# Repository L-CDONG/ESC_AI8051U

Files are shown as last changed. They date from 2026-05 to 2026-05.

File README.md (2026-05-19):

# STC8051U BLDC ESC – 无传感器无刷电子调速器

基于 **STC8051U** 单片机设计的 **无传感器无刷直流电机（BLDC）电子调速器（ESC）**，适用于无人机、小型电动工具

Snipaste_2026-05-19_12-56-54
Snipaste_2026-05-19_12-57-10

---

## 特性

- **主控芯片**：STC8051U（增强型8051内核，内置比较器/ADC，硬件PWM）
- **控制方式**：无传感器六步换向（120° 导通方式）
- **位置检测**：反电动势（BEMF）过零点检测，无需霍尔传感器
- **调制方式**：上桥臂PWM调制 + 下桥臂恒通（或互补PWM，根据配置可选）
- **启动方式**：三段式启动（预定位 → 强制换向 → 同步运行）
- **保护功能**：过流保护（通过ADC采样）、堵转保护、欠压保护
- **参数配置**：可通过串口（UART）在线调节PWM频率、启动参数等
- **开源协议**：MIT

---

## 工作原理

### 1. 六步换向法
三相BLDC的六个导通顺序（AB → AC → BC → BA → CA → CB），每60°电角度切换一次，每次导通两相（一相高端PWM，一相低端ON，第三相悬空）。

### 2. 反电动势过零点检测
- 悬空相的端电压与虚拟中性点电压比较（利用芯片内部比较器或外部电阻分压网络）
- 当BEMF过零点发生后，延迟30°电角度执行换相
- STC8051U内置比较器可直接用于过零检测，无需外部比较器芯片

### 3. 闭环控制
通过PWM占空比调节电机转速，根据换相周期计算实时转速，实现速度闭环（可扩展）。

---

## 硬件设计

### 主要元件清单

| 元件 | 型号/参数 | 数量 |
|---|---|---|
| MCU | STC8051U-40I-LQFP48 | 1 |
| MOSFET 驱动 | EG2181 / IR2101 (半桥) | 3 |
| N-MOSFET | 根据电压电流选择 (如 IRFS3607) | 6 |
| 电流采样电阻 | 0.001Ω ~ 0.01Ω 功率电阻 | 1 |
| 电压采样电阻分压 | 用于母线电压、反电动势 | 若干 |

### 典型电路结构

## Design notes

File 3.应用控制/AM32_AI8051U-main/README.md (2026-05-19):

# 80251 ESC Base on AI8051U

* [AM32](https://github.com/am32-firmware/AM32)<br>
* [ESC_Config_Tool](https://am32.ca/downloads)<br>
* [Bootloader](https://github.com/Icey7122/AM32_Bootloader_AI8051U)<br>

## Introduction
The AM32 firmware has been ported to the 80251 platform, and the controller has chosen as AI8051U. It can be compiled on Keil C251. At the same time, the bootloader program has been ported, and tool of Esc_Config_Tool_1_82_WIN can be used to configure and upgrade firmware for ESC.

## Hardware

### MCU
The resources of MCU([datasheet](https://www.stcaimcu.com/data/download/Datasheet/AI8051U.pdf)) are shown in the following figure,You can see that it has many peripheral resources.For more information, you can refer to the [STC](https://www.stcai.com/)<br>

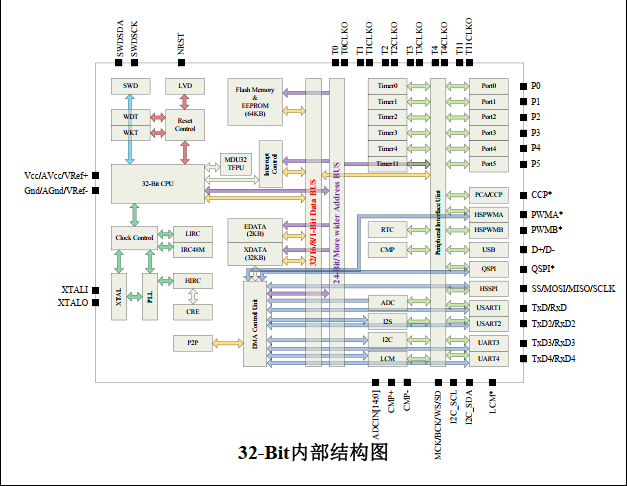
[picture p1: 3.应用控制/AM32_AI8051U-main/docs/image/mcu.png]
mcu


### MCU Pins Diagram
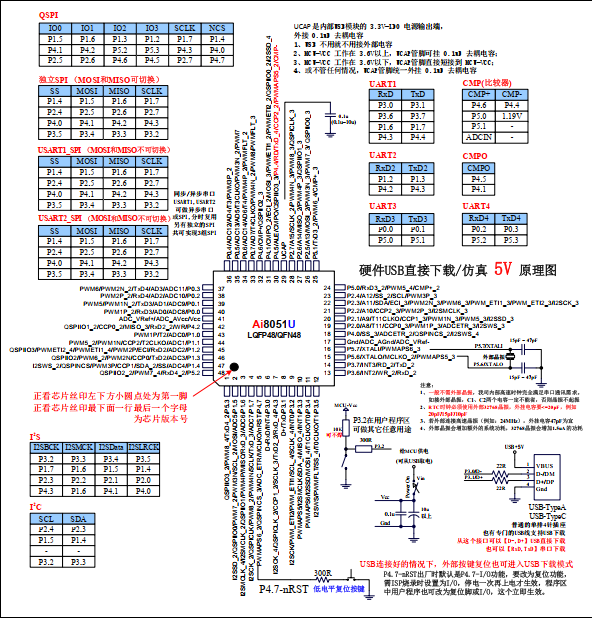
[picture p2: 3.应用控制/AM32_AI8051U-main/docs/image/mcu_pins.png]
mcu_Pins


Using PWMA to output 3 sets of complementary PWM for driving MOSFEET, Using PWMB for capturing external throttle signals, Using ADC to sample voltage and current, for low voltage protection and over current protection(But I'm not done yet). Using internal OPA and BEMF to estimate rotor position. TMR0 and TMR1 is used to calculate commutation time and motor timing.TMR2 is used for the serial port. TMR3 and TMR11 are used for the delay function (in fact, only one is needed). TMR4 is used to complete some periodic tasks.

### PINS
PINS

AH AL BH BL CH CL:  PWMA outputs;<br>
INPUT: PWMB used to capture external throttle signals;<br>
A_BEMF: A-Phase BEMF, connect to P46;<br>
B_BEMF: B-Phase BEMF, connect to P51;<br>
C_BEMF: C-Phase BEMF, connect to P50;<br>
CC_BEMF: Neutral point BEMF, connect to P45/P44(Note that for this mcu, P45 and P44 are the same pins);<br>
ADC_V: Voltage sampling channel;<br>
ADC_I: Current sampling channel;<br>
 
In order to unify the interrupt entry of OPA, the outputs of OPA are merged into P41, Using pin interrupts of P41 for zero crossing comparison processing.

P30 and P31 are used to download bootloader  via STC-LINK1, UART or internal USB.<br>

For detailed information, please refer to the schematic diagram.

## Config (New PCB)

### Flashing BootLoader
1. For empty chips, BootLoader needs to be flashed via STC-LINK1, UART or internal USB, Connect according to the diagram below.

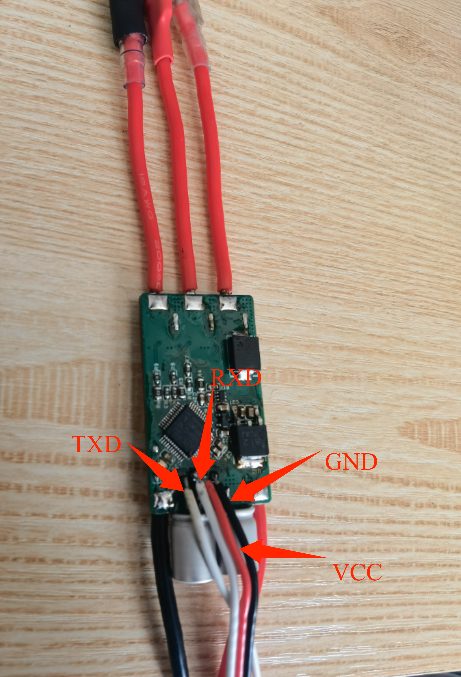
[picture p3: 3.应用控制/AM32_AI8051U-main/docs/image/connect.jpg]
connect
   

2. Open the [Bootloader project](https://github.com/Icey7122/AM32_Bootloader_AI8051U) using AIapp-ISP and download it directly after compilation.

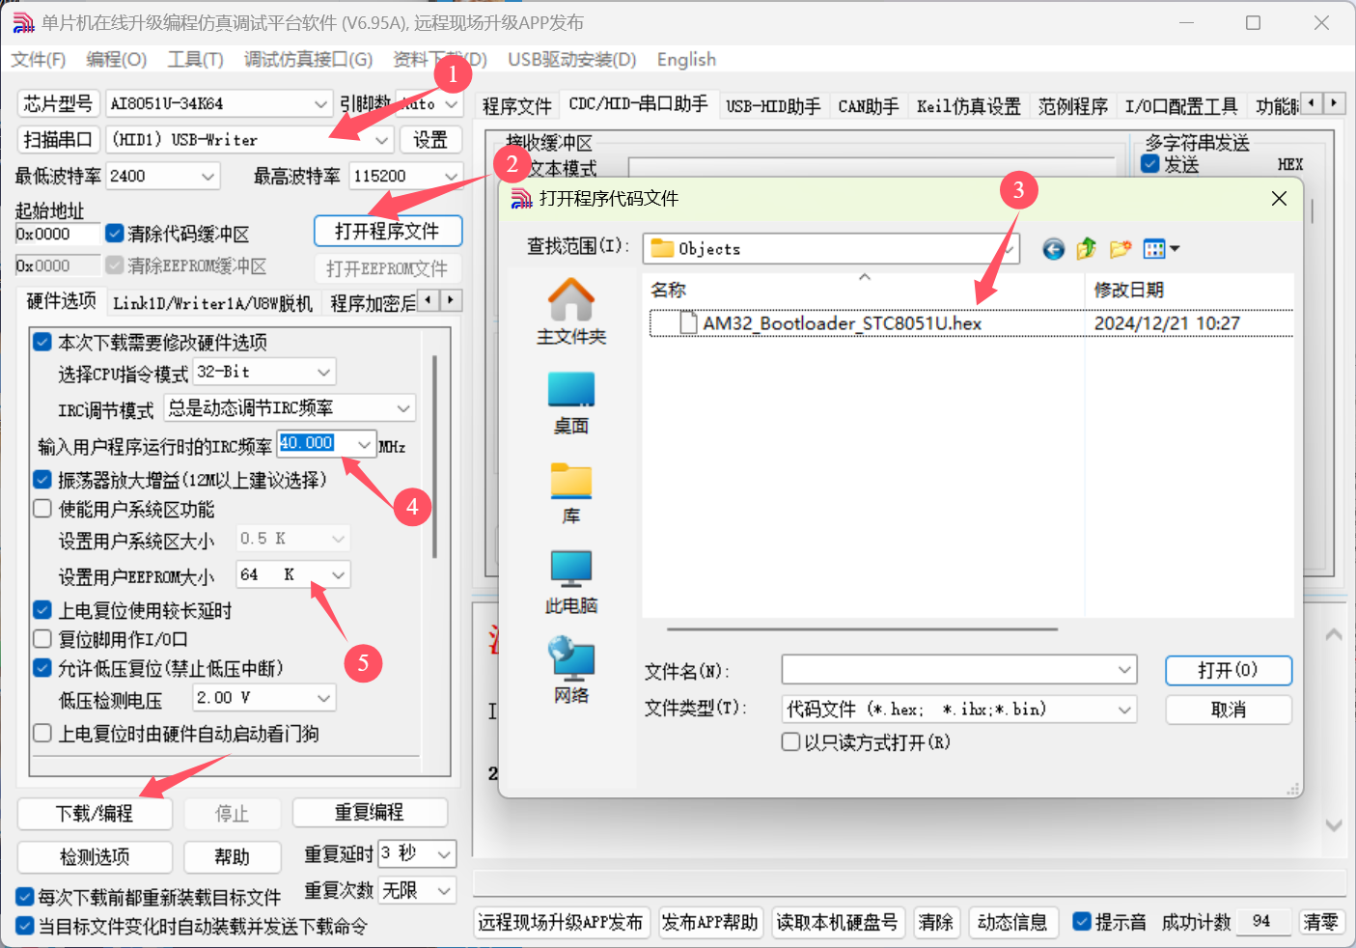
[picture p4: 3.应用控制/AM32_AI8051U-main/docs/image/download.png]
download
    

3. Use a one-wire serial port(You can connect the RX and TX of the USB to serial chip,such as CH340, together and then connect them to the board) to connect to ESC and use tools to configure and update firmware. I used CH340 to perfom, and the wiring is shown in the following figure.

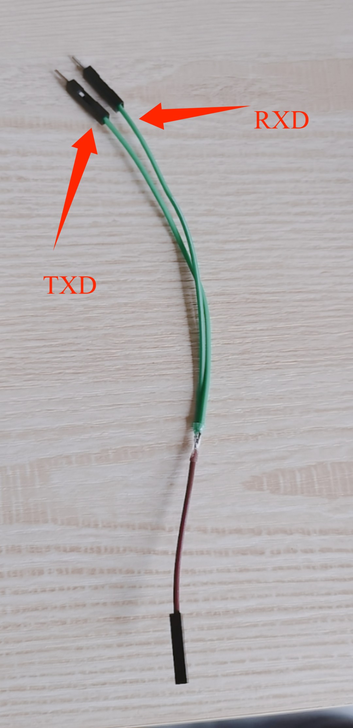
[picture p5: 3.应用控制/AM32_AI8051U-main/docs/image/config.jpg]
config
    
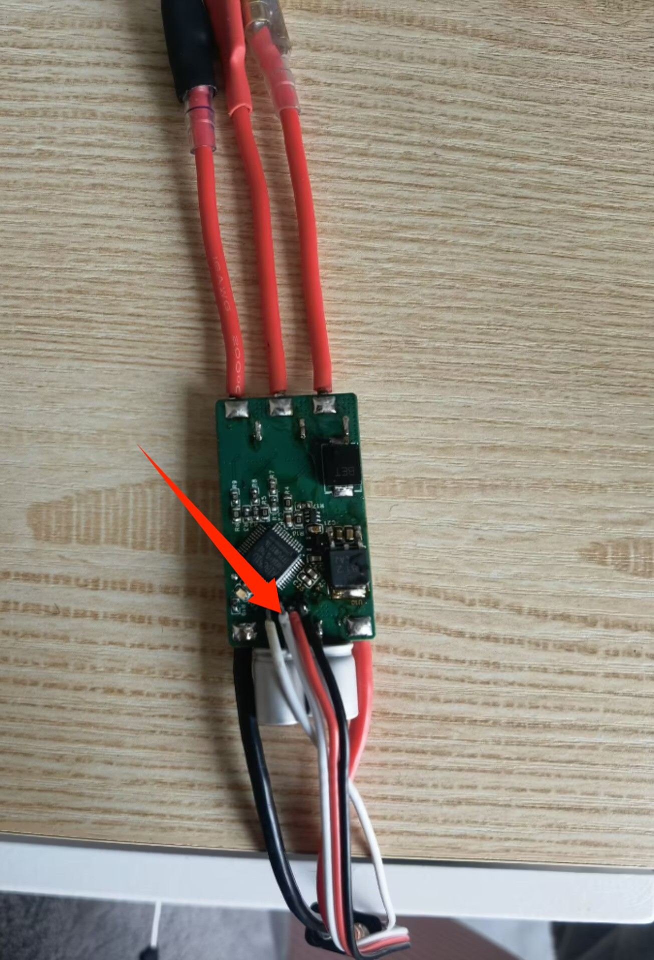
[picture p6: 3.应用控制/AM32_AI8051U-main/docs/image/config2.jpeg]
config
    

    If the Bootloader is burned correctly, Open the configuration tool ***Esc_Config_Tool_1_82_WIN.exe*** and power on the ESC. Follow the steps in the following figure to click. When connecting for the first time, <font color=red>*'No EEprom'*</font> will be displayed!
    
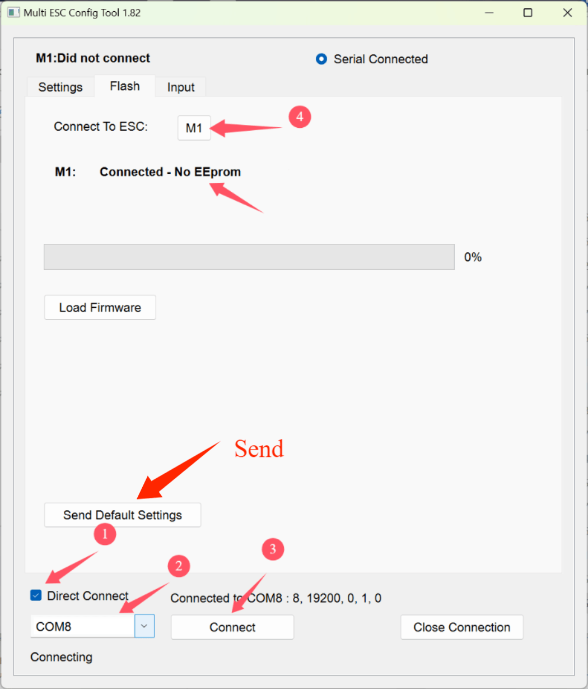
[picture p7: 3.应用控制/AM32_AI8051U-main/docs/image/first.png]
first
    

    Directly click on ***Send Default Settings*** below to burn the default values. After successful burning, power on again. Connect again and click ***M1***. The default parameters we just burned will be displayed.

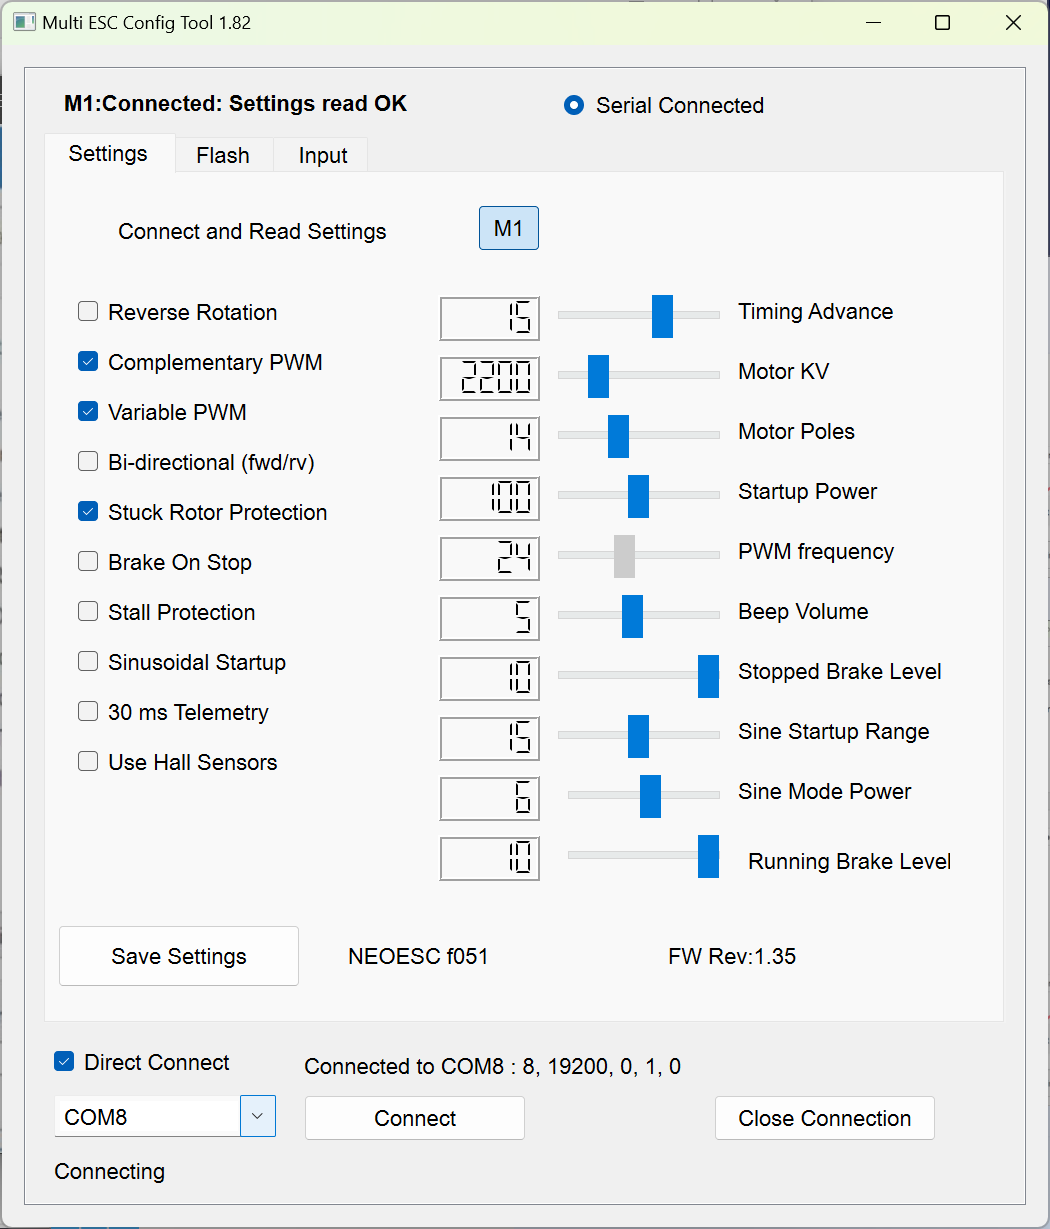
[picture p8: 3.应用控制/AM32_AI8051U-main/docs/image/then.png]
then
    

4. Flashing firmware and configurations<br>
    The firmware can be compiled using Keil C251, and the compiled firmware is in the ***\Objects*** folder.

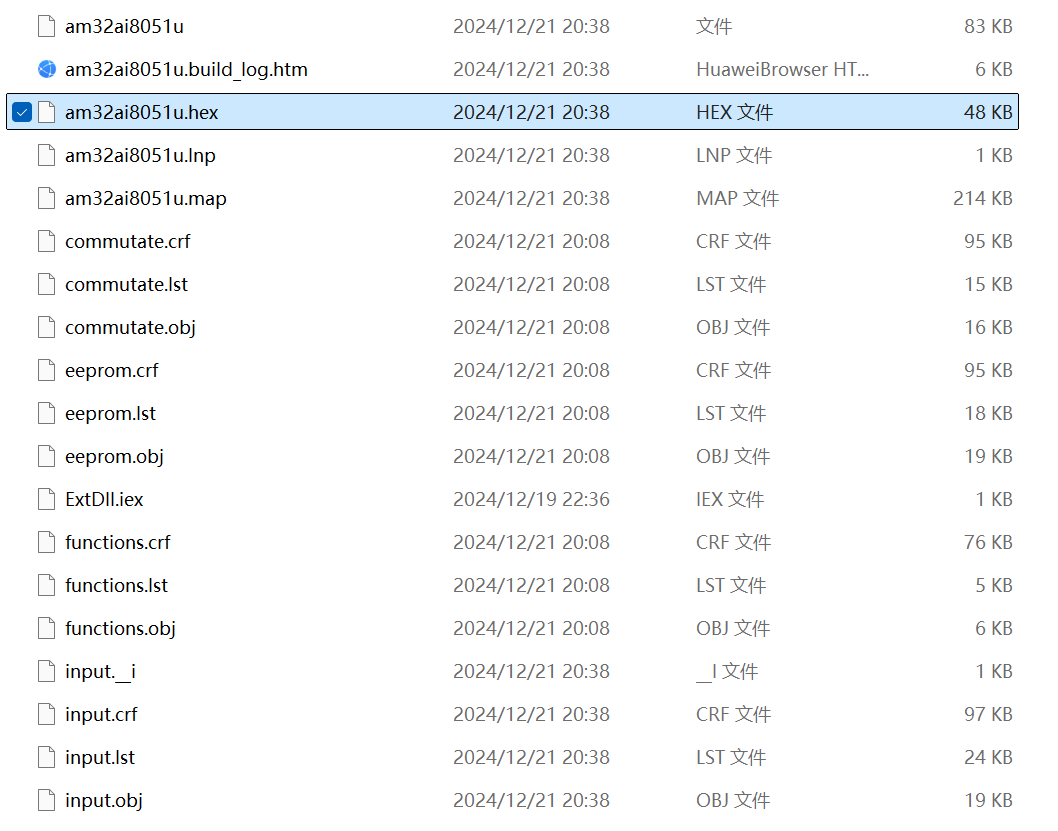
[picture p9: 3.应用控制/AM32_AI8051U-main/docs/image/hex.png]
hex
    

    Open the HEX file with a text editor.I prefer to use VScode.To support HEX file editing, you need to install the ***Hex Editor or Intel HEX format*** plug-in. The plug-in can be installed in the extension market. After installation, open the HEX file.

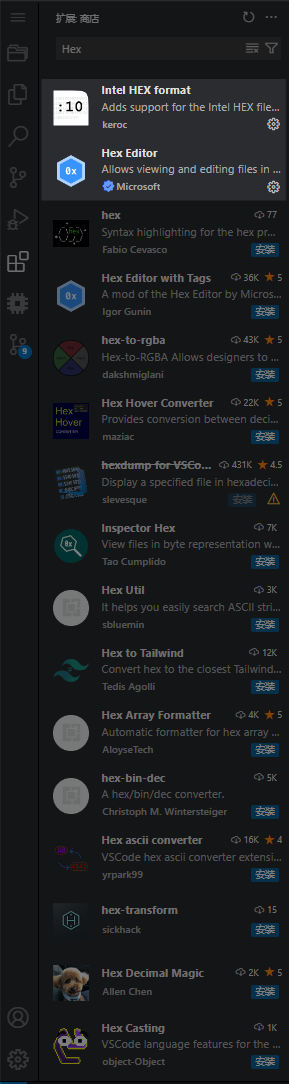
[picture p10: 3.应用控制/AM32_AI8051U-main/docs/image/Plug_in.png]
plug-in
    

    In this HEX file, please pay attention to the first line.<br>
    :03**0000**00023E58**65**<br>
    You should change the value of the **0000** to **1000** and the value of the **65** to **55**. Then save the file.<br>
    :03**1000**00023E58**55**<br>
    Note that the value of the **0000** is the starting address of the program, and the value of the **65** is the checksum. The value of the **1000** is the starting address of the program after the bootloader is burned. The value of the **55** is the new checksum. The starting address of the program after the bootloader is burned is 0x1000, so the value of the **0000** is changed to **1000**. The checksum is calculated by adding all the data in the line except the starting colon and the checksum itself, and then taking the two's complement of the last byte of the sum. The value of the **65** is changed to **55**. The specific calculation method can be found in the [link](https://en.wikipedia.org/wiki/Intel_HEX).
    If you use VScode with the plug-in, you can directly click on the **address value** to modify it, and the plug-in may automatically calculate the new checksum.

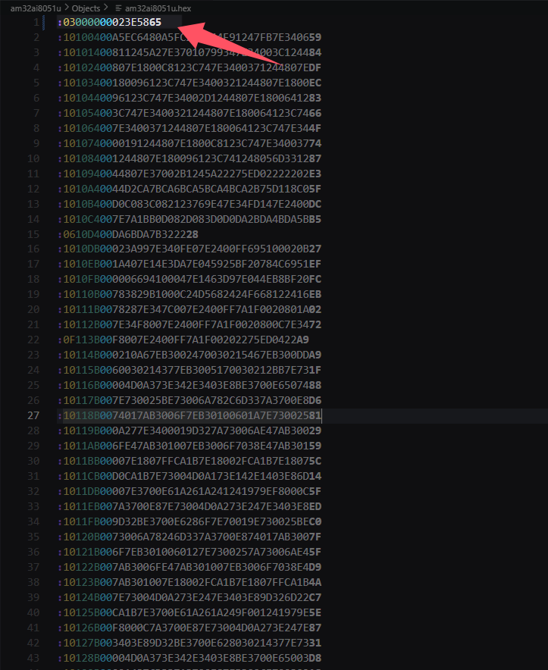
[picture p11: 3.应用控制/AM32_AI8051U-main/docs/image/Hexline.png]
Hexline
    
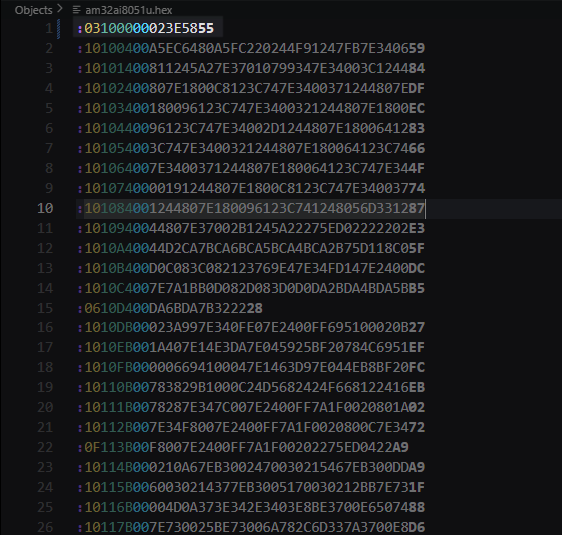
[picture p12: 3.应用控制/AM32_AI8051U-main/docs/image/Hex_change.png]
Hexchange
    
   
   Returning to the FLASH interface of the tool, we click on ***Load Firmware***, select the firmware we just modified, and the ***FLash Firmware*** button will pop up. Click to start updating the program. 

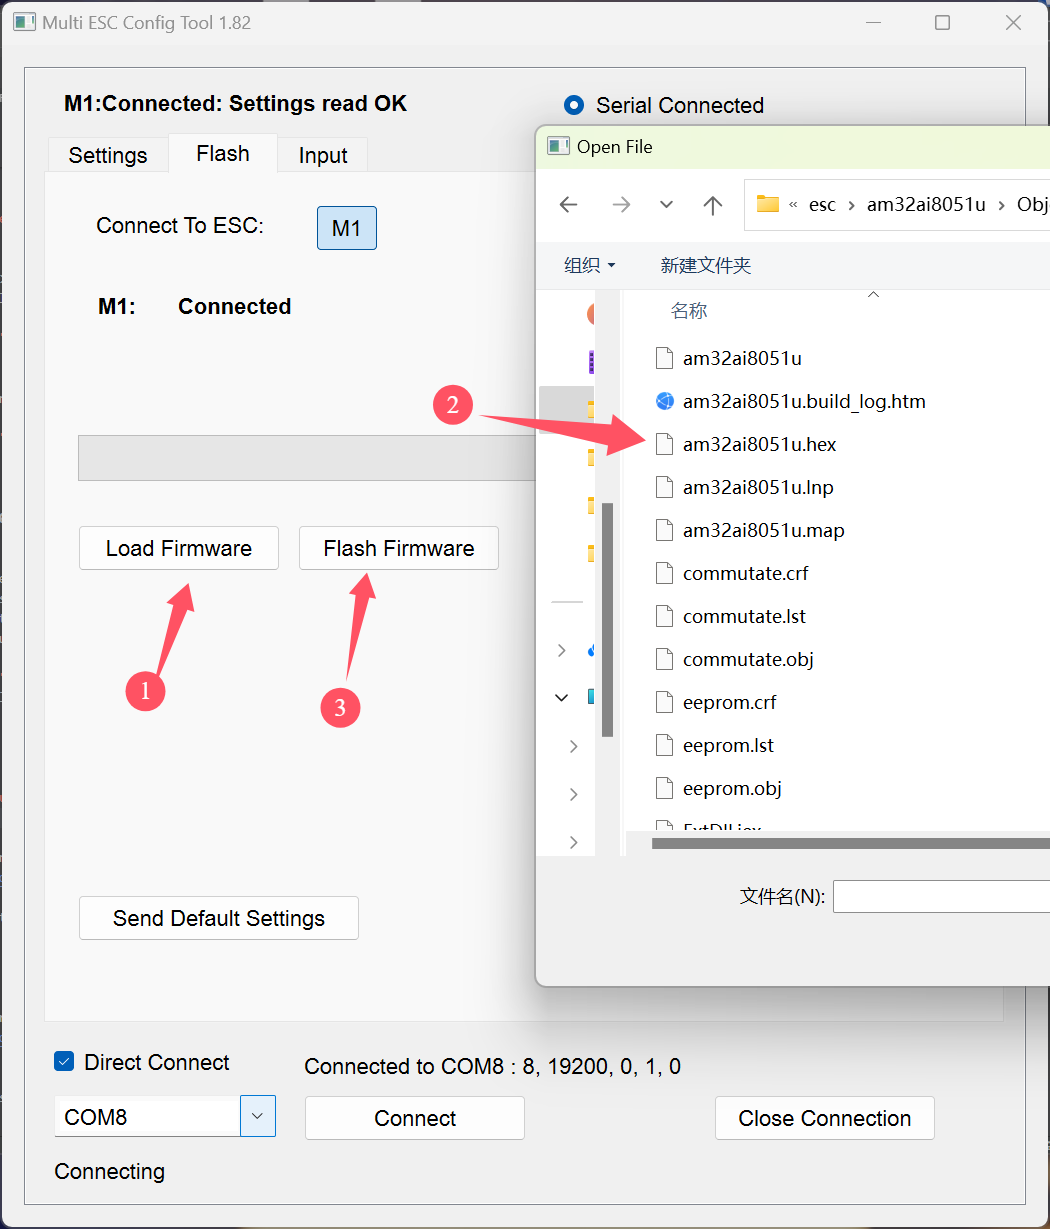
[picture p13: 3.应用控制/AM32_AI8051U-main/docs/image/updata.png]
updata
    

    After the update is completed, power on again and connect ESC again to configure ESC. The specific meaning of configuration values can be found in the following [links](https://github.com/AlkaMotors/AM32-MultiRotor-ESC-firmware/wiki/ESC-Settings-Explained).

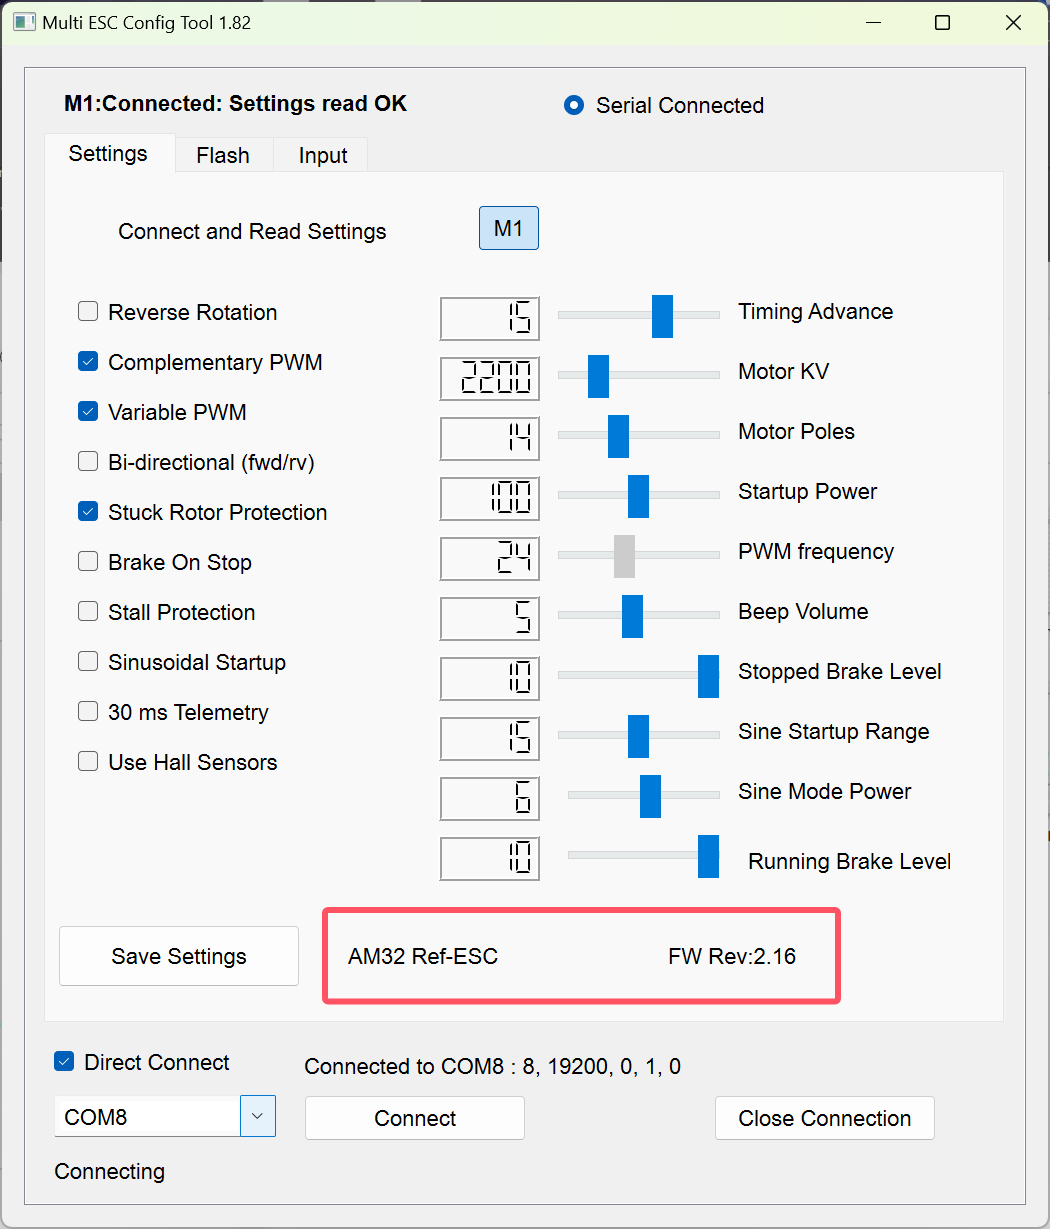
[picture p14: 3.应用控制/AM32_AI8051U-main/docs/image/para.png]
para
    

## Hardware design
The circuit design is located in docs: [pcb](https://github.com/Icey7122/AM32_AI8051U/tree/main/docs), and the design is carried out using KiCAD, please note that the design is not particularly reasonable, please refer to it carefully.(Now I redesign the PCB on LCEDA, and the new PCB project also in docs folder.)

   New design:
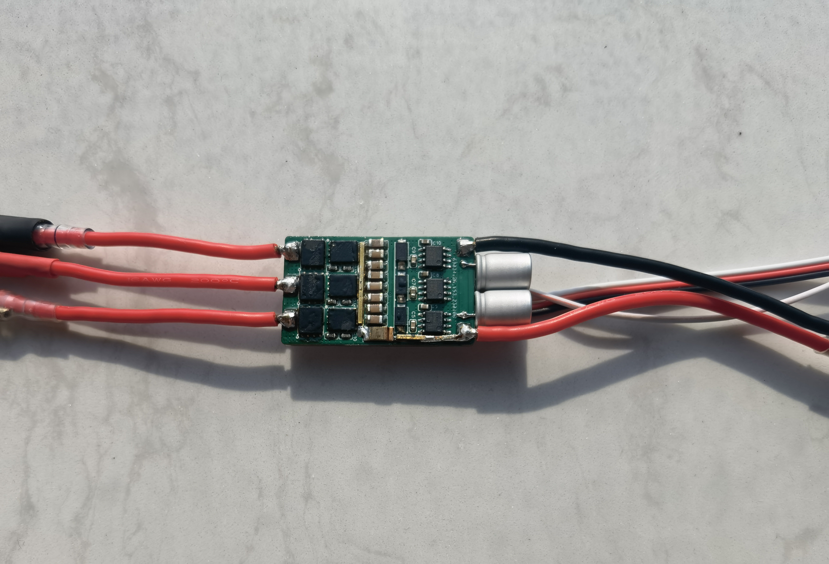
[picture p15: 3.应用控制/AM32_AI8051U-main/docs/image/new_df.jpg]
new_f
   
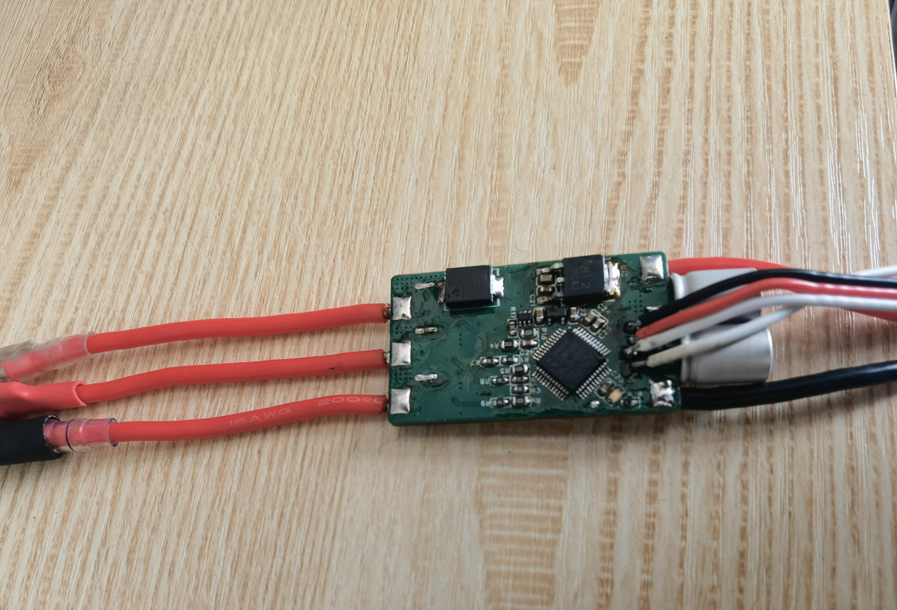
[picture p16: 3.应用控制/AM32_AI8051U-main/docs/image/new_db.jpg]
new_b
   

## Test

The version I ported is V2.16, which supports signals such as dshot300, dshot600, and PWM.(But for some reason, I only implemented PWM, dshot can't be used).
* [Test Video(old PCB)](https://www.bilibili.com/video/BV1eZkvYuEUj)
* [Test Video(new PCB)](https://www.bilibili.com/video/BV1Huc3e8Egv)
## Reference
* [AM32](https://github.com/am32-firmware/AM32)
* [RISC-V AM32](https://github.com/TianpeiLee/AM32)

## Thanks
* HDU students have discovered some porting bugs, these bugs caused the ESC to be slow to respond.

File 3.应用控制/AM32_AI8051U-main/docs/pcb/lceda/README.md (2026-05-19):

# LCEDA PCB
* [PCB](https://oshwhub.com/lcet7122/stc-am32-firmware-porting)<br>

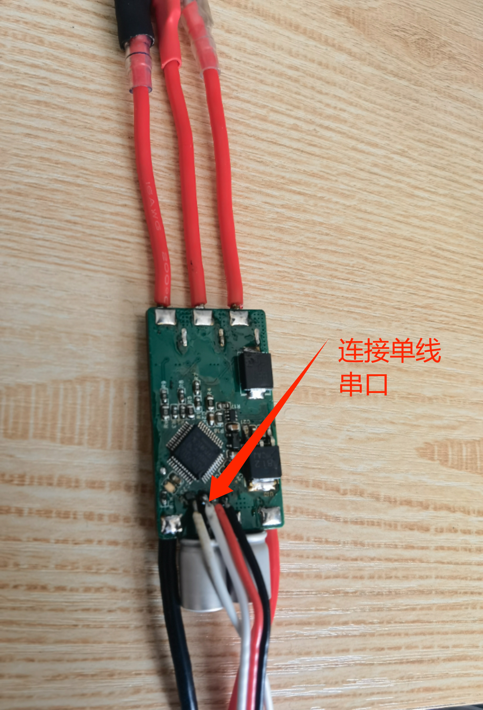
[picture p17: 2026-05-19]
3.应用控制/AM32_AI8051U-main/docs/image/config3.jpg

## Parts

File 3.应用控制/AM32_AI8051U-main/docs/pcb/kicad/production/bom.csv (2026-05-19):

Designator | Footprint | Quantity | Value | LCSC Part #
C1, C19, C20, C28, C29, C30, C31 | 0603 | 7 | 0.1uF
C10, C15, C5 | 0603 | 3 | C
C11, C12, C13, C16, C17, C18, C6, C7, C8 | 1206 | 9 | C
C14, C4, C9 | 0805 | 3 | C
C2, C24, C26 | 0603 | 3 | 10uF
C21, C27 | 0603 | 2 | 4.7uF
C22 | CP_EIA-6032-15_Kemet-U_Pad2.25x2.35mm_HandSolder | 1 | 330uF
C23 | 0603 | 1 | 0.01uF
C25 | 0603 | 1 | 100nF
C3 | 0603 | 1 | 1uF
C32 | CP_Radial_D10.0mm_P5.00mm | 1 | C_Polarized
D1, D10, D11, D14, D15, D16, D17, D4, D5, D6, D9 | D_SMA_Handsoldering | 11 | SS54
D12, D13, D2, D3, D7, D8 | D_SOD-323_HandSoldering | 6 | 1N5819
D18, D19 | 0603 | 2 | LED
J1, J6 | USB_C_Receptacle_GCT_USB4105-xx-A_16P_TopMnt_Horizontal | 2 | USB_C_Receptacle_USB2.0_16P
J2, J3, J4, J5 | PinHeader_1x03_P2.54mm_Vertical | 4 | Conn_01x03_Pin
L1, L2 | L_6.3x6.3_H3 | 2 | 10uH
Q1, Q2, Q3, Q4, Q5, Q6 | Infineon_PG-TDSON-8 | 6 | TPH1R005PL
R1 | 0603 | 1 | 0R
R10, R17, R20, R30, R33, R34, R5, R6, R7, R8, R9 | 0603 | 11 | 10K
R11, R12, R13, R14, R15, R16 | 0603 | 6 | 10R
R18 | 0603 | 1 | 2.6K
R19 | 0603 | 1 | 1.11K
R2, R27, R28, R29, R3, R4 | 0603 | 6 | 1K
R21 | 0603 | 1 | 6.38K
R22 | 0603 | 1 | 100K
R23, R24, R26, R31, R32 | 0603 | 5 | 5.1K
R25 | 2512 | 1 | R_2512
SW1, SW2 | SW_SPST_CK_RS282G05A3 | 2 | SW_Push
U1 | LQFP-48_7x7mm_P0.5mm | 1 | STC8051U-32Kx
U2, U3, U4 | SOP-8_5.28x5.23mm_P1.27mm | 3 | EG2181
U5 | SOIC-8-1EP_3.9x4.9mm_P1.27mm_EP2.29x3mm | 1 | TPS5450
U6 | HSOP-8-1EP_3.9x4.9mm_P1.27mm_EP2.3x2.3mm | 1 | RT9048
U7 | SOT-23-6 | 1 | MT3608
U8 | SOT-363_SC-70-6 | 1 | INA199xxDCK
U9 | SOIC-8_3.9x4.9mm_P1.27mm | 1 | CH330N

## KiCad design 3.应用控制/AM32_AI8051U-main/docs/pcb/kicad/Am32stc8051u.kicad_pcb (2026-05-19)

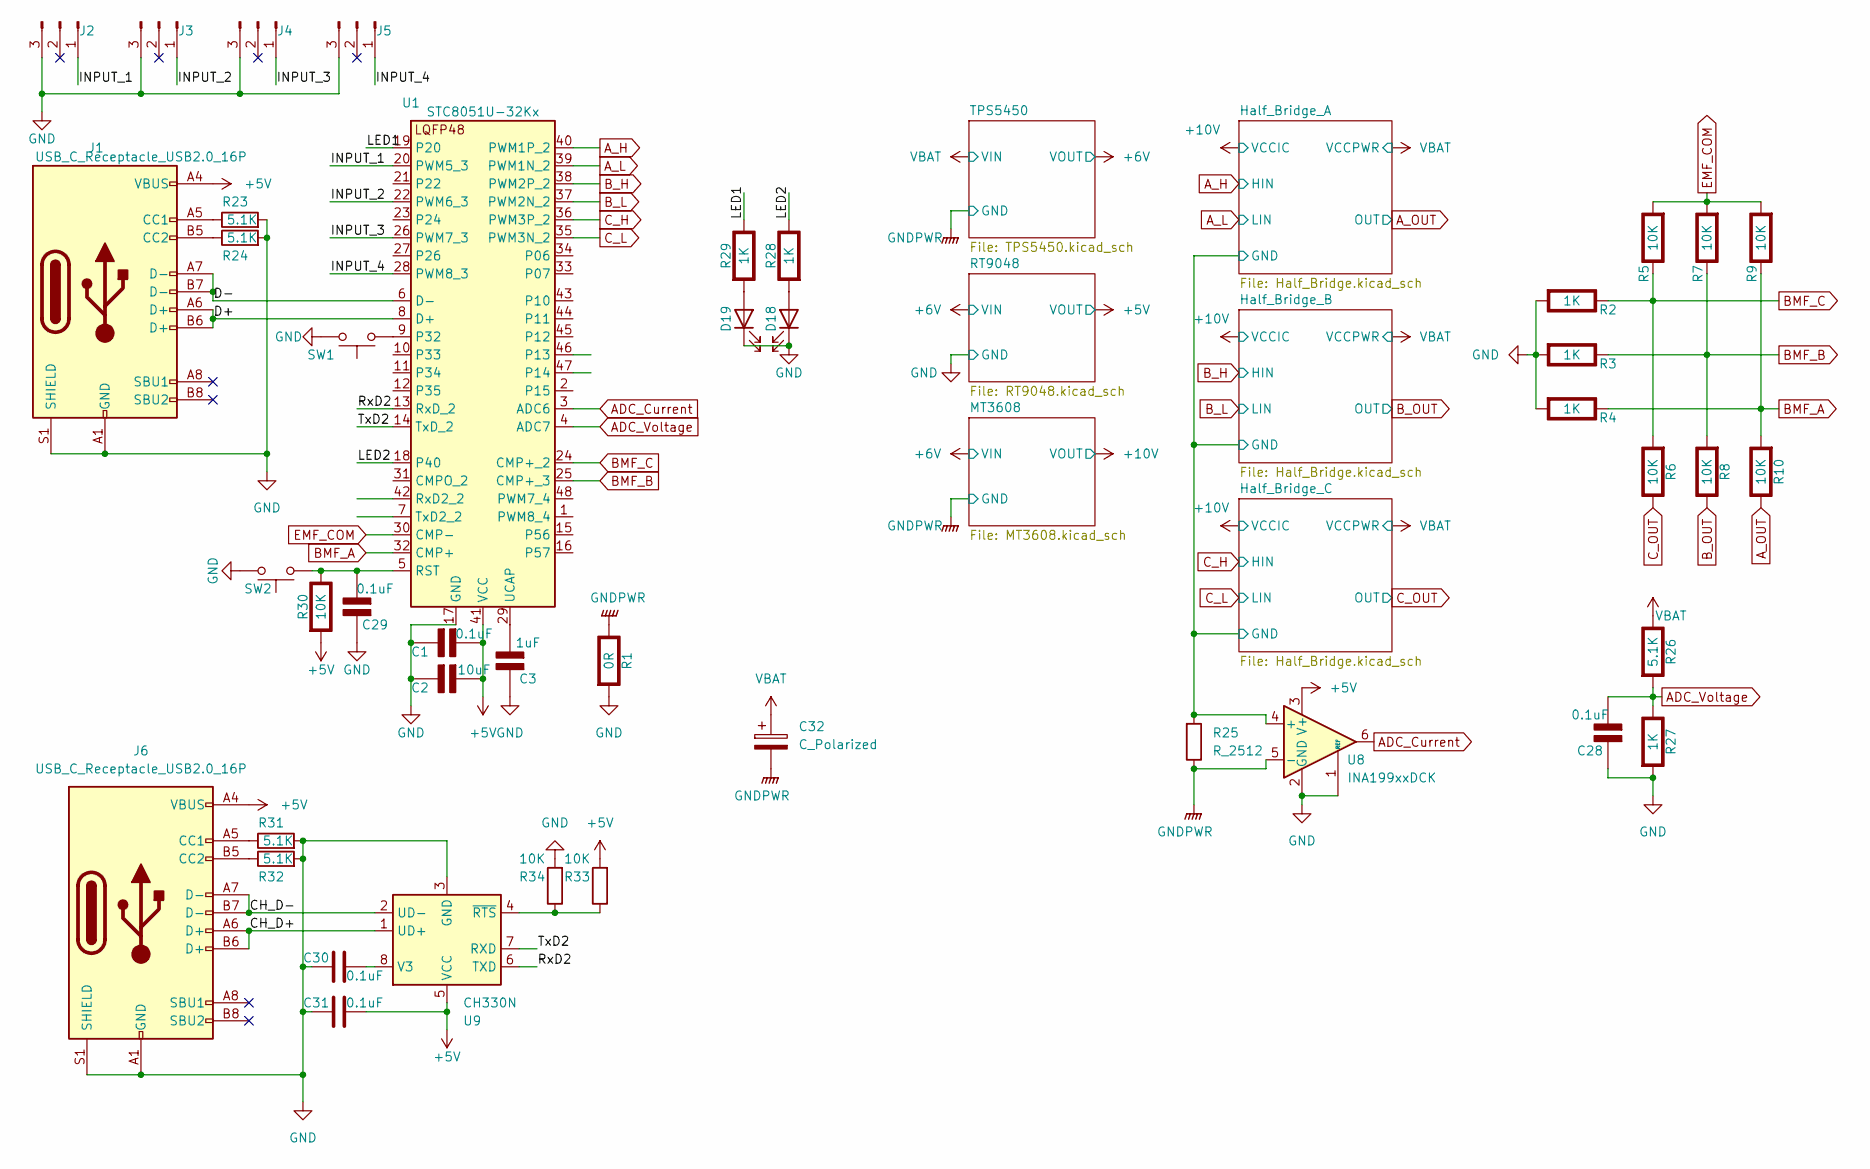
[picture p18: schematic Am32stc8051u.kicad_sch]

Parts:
C1, C28, C29: 0.1uF; C_0603_1608Metric_Pad1.08x0.95mm_HandSolder; Rating V
C2: 10uF; C_0603_1608Metric_Pad1.08x0.95mm_HandSolder; Rating V
C3: 1uF; C_0603_1608Metric_Pad1.08x0.95mm_HandSolder; Rating V
C30, C31: 0.1uF; C_0603_1608Metric_Pad1.08x0.95mm_HandSolder
C32: C_Polarized; CP_Radial_D10.0mm_P5.00mm
D18, D19: LED; LED_0603_1608Metric_Pad1.05x0.95mm_HandSolder
J1, J6: USB_C_Receptacle_USB2.0_16P; USB_C_Receptacle_GCT_USB4105-xx-A_16P_TopMnt_Horizontal
J2, J3, J4, J5: Conn_01x03_Pin; PinHeader_1x03_P2.54mm_Vertical
R1: 0R; R_0603_1608Metric_Pad0.98x0.95mm_HandSolder; Rating W
R2, R3, R4, R27, R28, R29: 1K; R_0603_1608Metric_Pad0.98x0.95mm_HandSolder; Rating W
R5, R6, R7, R8, R9, R10, R30: 10K; R_0603_1608Metric_Pad0.98x0.95mm_HandSolder; Rating W
R23, R24, R31, R32: 5.1K; R_0603_1608Metric_Pad0.98x0.95mm_HandSolder
R25: R_2512; R_2512_6332Metric
R26: 5.1K; R_0603_1608Metric_Pad0.98x0.95mm_HandSolder; Rating W
R33, R34: 10K; R_0603_1608Metric_Pad0.98x0.95mm_HandSolder
SW1, SW2: SW_Push; SW_SPST_CK_RS282G05A3
U1: STC8051U-32Kx; LQFP-48_7x7mm_P0.5mm
U8: INA199xxDCK; SOT-363_SC-70-6
U9: CH330N; SOIC-8_3.9x4.9mm_P1.27mm

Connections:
+5V: C1.1 (+), C2.1 (+), C31.2, J1.A4 (VBUS), J1.A9 (VBUS), J1.B4 (VBUS), J1.B9 (VBUS), J6.A4 (VBUS), J6.A9 (VBUS), J6.B4 (VBUS), J6.B9 (VBUS), R30.2 (-), R33.2, U1.41 (VCC), U8.3 (V+), U9.5 (VCC); also elsewhere on the board
/CH_D+: J6.A6 (D+), J6.B6 (D+), U9.1 (UD+)
/CH_D-: J6.A7 (D-), J6.B7 (D-), U9.2 (UD-)
/D+: J1.A6 (D+), J1.B6 (D+), U1.8 (D+)
/D-: J1.A7 (D-), J1.B7 (D-), U1.6 (D-)
/Half_Bridge_A/GND: R25.1, U8.4 (+); also elsewhere on the board
/INPUT_1: J2.1, U1.20 (PWM5_3)
/INPUT_2: J3.1, U1.22 (PWM6_3)
/INPUT_3: J4.1, U1.26 (PWM7_3)
/INPUT_4: J5.1, U1.28 (PWM8_3)
/LED1: R29.1 (+), U1.19 (P20)
/LED2: R28.1 (+), U1.18 (P40)
/RxD2: U1.13 (RxD_2), U9.6 (TXD)
/TxD2: U1.14 (TxD_2), U9.7 (RXD)
ADC_Current: U1.3 (ADC6), U8.6
ADC_Voltage: C28.2 (-), R26.2 (-), R27.1 (+), U1.4 (ADC7)
A_H: U1.40 (PWM1P_2); also elsewhere on the board
A_L: U1.39 (PWM1N_2); also elsewhere on the board
A_OUT: R10.1 (+); also elsewhere on the board
BMF_A: R4.1 (+), R9.1 (+), R10.2 (-), U1.32 (CMP+)
BMF_B: R3.1 (+), R7.1 (+), R8.2 (-), U1.25 (CMP+_3)
BMF_C: R2.1 (+), R5.1 (+), R6.2 (-), U1.24 (CMP+_2)
B_H: U1.38 (PWM2P_2); also elsewhere on the board
B_L: U1.37 (PWM2N_2); also elsewhere on the board
B_OUT: R8.1 (+); also elsewhere on the board
C_H: U1.36 (PWM3P_2); also elsewhere on the board
C_L: U1.35 (PWM3N_2); also elsewhere on the board
C_OUT: R6.1 (+); also elsewhere on the board
EMF_COM: R5.2 (-), R7.2 (-), R9.2 (-), U1.30 (CMP-)
GND: C1.2 (-), C2.2 (-), C3.1 (+), C28.1 (+), C29.1 (+), C30.1, C31.1, D18.1 (K), D19.1 (K), J1.A1 (GND), J1.A12 (GND), J1.B1 (GND), J1.B12 (GND), J1.S1 (SHIELD), J2.3, J3.3, J4.3, J5.3, J6.A1 (GND), J6.A12 (GND), J6.B1 (GND), J6.B12 (GND), J6.S1 (SHIELD), R1.2 (-), R2.2 (-), R3.2 (-), R4.2 (-), R23.2, R24.2, R27.2 (-), R31.2, R32.2, R34.2, SW1.1, SW2.1, U1.17 (GND), U8.1 (REF), U8.2 (GND), U9.3 (GND); also elsewhere on the board
GNDPWR: C32.2, R1.1 (+), R25.2, U8.5 (-); also elsewhere on the board
unnamed: C3.2 (-), U1.29 (UCAP)
unnamed: C29.2 (-), R30.1 (+), SW2.2, U1.5 (RST)
unnamed: D18.2 (A), R28.2 (-)
unnamed: D19.2 (A), R29.2 (-)
unnamed: J1.A5 (CC1), R23.1
unnamed: J1.B5 (CC2), R24.1
unnamed: J6.A5 (CC1), R31.1
unnamed: J6.B5 (CC2), R32.1
unnamed: SW1.2, U1.9 (P32)
unnamed: C30.2, U9.8 (V3)
unnamed: R33.1, R34.1, U9.4 (~RTS)
VBAT: C32.1, R26.1 (+); also elsewhere on the board

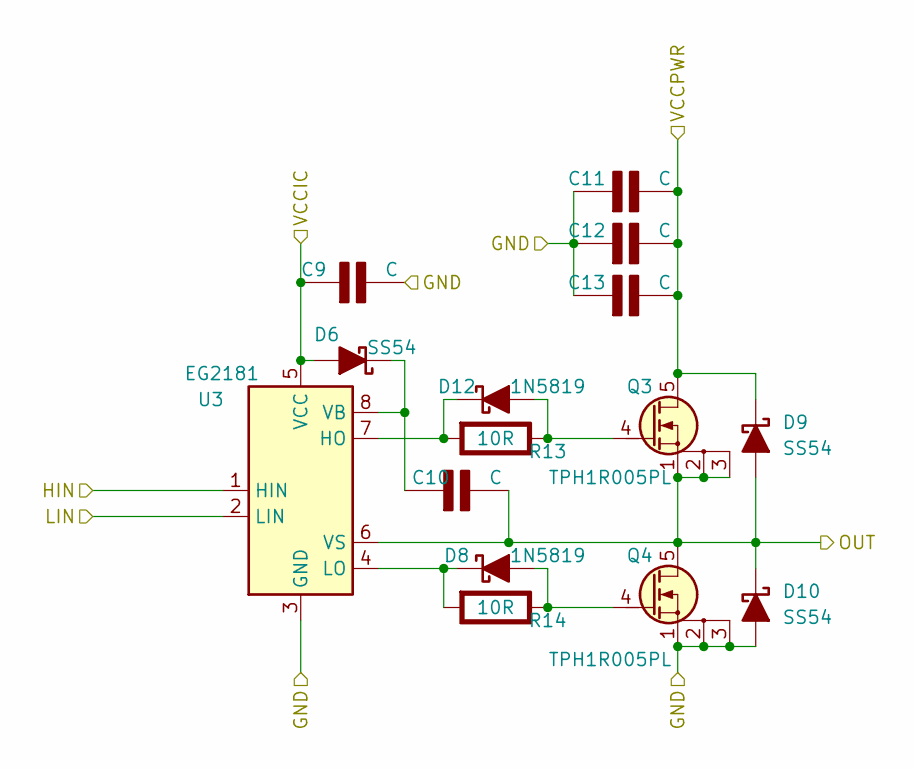
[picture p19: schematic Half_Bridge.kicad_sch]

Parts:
C9: C; C_0805_2012Metric_Pad1.18x1.45mm_HandSolder; Rating V
C10: C; C_0603_1608Metric_Pad1.08x0.95mm_HandSolder; Rating V
C11, C12, C13: C; C_1206_3216Metric_Pad1.33x1.80mm_HandSolder; Rating V
D6, D9, D10: SS54; D_SMA_Handsoldering
D8, D12: 1N5819; D_SOD-323_HandSoldering
Q3, Q4: TPH1R005PL; Infineon_PG-TDSON-8
R13, R14: 10R; R_0603_1608Metric_Pad0.98x0.95mm_HandSolder; Rating W
U3: EG2181; SOP-8_5.28x5.23mm_P1.27mm

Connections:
+10V: C9.1 (+), D6.2 (A), U3.5 (VCC); also elsewhere on the board
/Half_Bridge_A/GND: C9.2 (-), C11.1 (+), C12.1 (+), C13.1 (+), D10.2 (A), Q4.1 (S), Q4.2 (S), Q4.3 (S), U3.3 (GND); also elsewhere on the board
B_H: U3.1 (HIN); also elsewhere on the board
B_L: U3.2 (LIN); also elsewhere on the board
B_OUT: C10.2 (-), D9.2 (A), D10.1 (K), Q3.1 (S), Q3.2 (S), Q3.3 (S), Q4.5 (D), U3.6 (VS); also elsewhere on the board
unnamed: C10.1 (+), D6.1 (K), U3.8 (VB)
unnamed: D8.2 (A), Q4.4 (G), R14.1 (+)
unnamed: D8.1 (K), R14.2 (-), U3.4 (LO)
VBAT: C11.2 (-), C12.2 (-), C13.2 (-), D9.1 (K), Q3.5 (D); also elsewhere on the board

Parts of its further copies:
C4, C14: C; C_0805_2012Metric_Pad1.18x1.45mm_HandSolder; Rating V
C5, C15: C; C_0603_1608Metric_Pad1.08x0.95mm_HandSolder; Rating V
C6, C7, C8, C16, C17, C18: C; C_1206_3216Metric_Pad1.33x1.80mm_HandSolder; Rating V
D1, D4, D5, D11, D14, D15: SS54; D_SMA_Handsoldering
D2, D3, D7, D13: 1N5819; D_SOD-323_HandSoldering
Q1, Q2, Q5, Q6: TPH1R005PL; Infineon_PG-TDSON-8
R11, R12, R15, R16: 10R; R_0603_1608Metric_Pad0.98x0.95mm_HandSolder; Rating W
U2, U4: EG2181; SOP-8_5.28x5.23mm_P1.27mm

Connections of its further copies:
+10V: C4.1 (+), C14.1 (+), D1.2 (A), D11.2 (A), U2.5 (VCC), U4.5 (VCC); also elsewhere on the board
/Half_Bridge_A/GND: C4.2 (-), C6.1 (+), C7.1 (+), C8.1 (+), C14.2 (-), C16.1 (+), C17.1 (+), C18.1 (+), D5.2 (A), D15.2 (A), Q2.1 (S), Q2.2 (S), Q2.3 (S), Q6.1 (S), Q6.2 (S), Q6.3 (S), U2.3 (GND), U4.3 (GND); also elsewhere on the board
A_H: U2.1 (HIN); also elsewhere on the board
A_L: U2.2 (LIN); also elsewhere on the board
A_OUT: C5.2 (-), D4.2 (A), D5.1 (K), Q1.1 (S), Q1.2 (S), Q1.3 (S), Q2.5 (D), U2.6 (VS); also elsewhere on the board
C_H: U4.1 (HIN); also elsewhere on the board
C_L: U4.2 (LIN); also elsewhere on the board
C_OUT: C15.2 (-), D14.2 (A), D15.1 (K), Q5.1 (S), Q5.2 (S), Q5.3 (S), Q6.5 (D), U4.6 (VS); also elsewhere on the board
unnamed: C5.1 (+), D1.1 (K), U2.8 (VB)
unnamed: C15.1 (+), D11.1 (K), U4.8 (VB)
unnamed: D2.2 (A), Q1.4 (G), R11.1 (+)
unnamed: D2.1 (K), R11.2 (-), U2.7 (HO)
unnamed: D3.2 (A), Q2.4 (G), R12.1 (+)
unnamed: D3.1 (K), R12.2 (-), U2.4 (LO)
unnamed: D13.2 (A), Q6.4 (G), R16.1 (+)
unnamed: D13.1 (K), R16.2 (-), U4.4 (LO)
VBAT: C6.2 (-), C7.2 (-), C8.2 (-), C16.2 (-), C17.2 (-), C18.2 (-), D4.1 (K), D14.1 (K), Q1.5 (D), Q5.5 (D); also elsewhere on the board

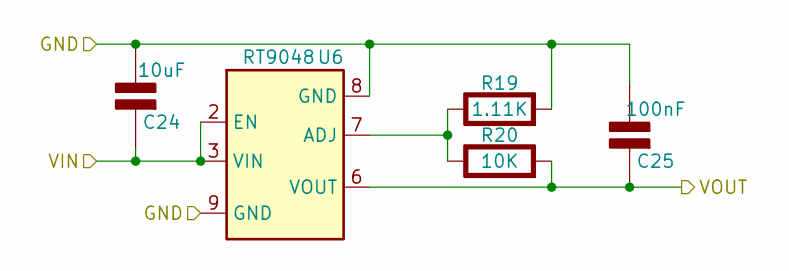
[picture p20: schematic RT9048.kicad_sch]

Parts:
C24: 10uF; C_0603_1608Metric_Pad1.08x0.95mm_HandSolder; Rating V
C25: 100nF; C_0603_1608Metric_Pad1.08x0.95mm_HandSolder; Rating V
R19: 1.11K; R_0603_1608Metric_Pad0.98x0.95mm_HandSolder; Rating W
R20: 10K; R_0603_1608Metric_Pad0.98x0.95mm_HandSolder; Rating W
U6: RT9048; HSOP-8-1EP_3.9x4.9mm_P1.27mm_EP2.3x2.3mm

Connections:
+5V: C25.1 (+), R20.2 (-), U6.6 (VOUT); also elsewhere on the board
+6V: C24.1 (+), U6.2 (EN), U6.3 (VIN); also elsewhere on the board
GND: C24.2 (-), C25.2 (-), R19.2 (-), U6.8 (GND), U6.9 (GND); also elsewhere on the board
unnamed: R19.1 (+), R20.1 (+), U6.7 (ADJ)

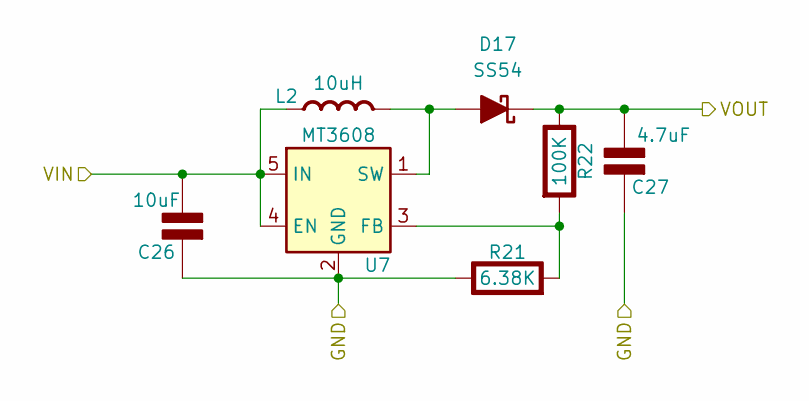
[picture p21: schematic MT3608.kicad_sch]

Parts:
C26: 10uF; C_0603_1608Metric_Pad1.08x0.95mm_HandSolder; Rating V
C27: 4.7uF; C_0603_1608Metric_Pad1.08x0.95mm_HandSolder; Rating V
D17: SS54; D_SMA_Handsoldering
L2: 10uH; L_6.3x6.3_H3; Rating A
R21: 6.38K; R_0603_1608Metric_Pad0.98x0.95mm_HandSolder; Rating W
R22: 100K; R_0603_1608Metric_Pad0.98x0.95mm_HandSolder; Rating W
U7: MT3608; SOT-23-6

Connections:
+6V: C26.2 (-), L2.1 (+), U7.4 (EN), U7.5 (IN); also elsewhere on the board
+10V: C27.2 (-), D17.1 (K), R22.1 (+); also elsewhere on the board
GNDPWR: C26.1 (+), C27.1 (+), R21.1 (+), U7.2 (GND); also elsewhere on the board
unnamed: D17.2 (A), L2.2 (-), U7.1 (SW)
unnamed: R21.2 (-), R22.2 (-), U7.3 (FB)

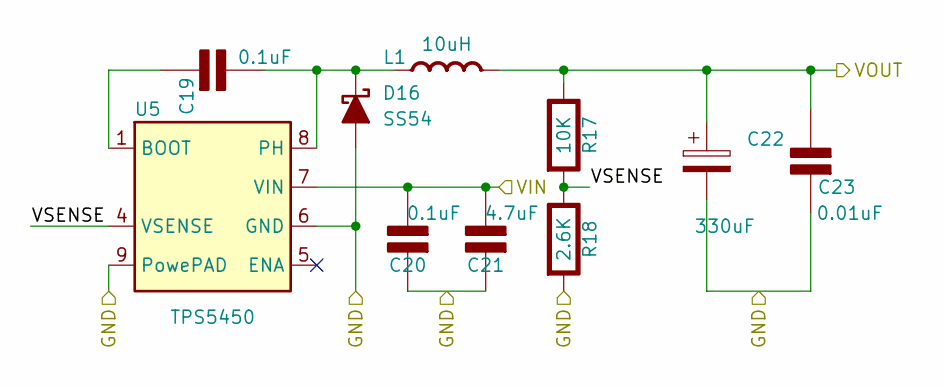
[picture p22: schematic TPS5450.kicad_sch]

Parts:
C19, C20: 0.1uF; C_0603_1608Metric_Pad1.08x0.95mm_HandSolder; Rating V
C21: 4.7uF; C_0603_1608Metric_Pad1.08x0.95mm_HandSolder; Rating V
C22: 330uF; CP_EIA-6032-15_Kemet-U_Pad2.25x2.35mm_HandSolder
C23: 0.01uF; C_0603_1608Metric_Pad1.08x0.95mm_HandSolder; Rating V
D16: SS54; D_SMA_Handsoldering
L1: 10uH; L_6.3x6.3_H3; Rating A
R17: 10K; R_0603_1608Metric_Pad0.98x0.95mm_HandSolder; Rating W
R18: 2.6K; R_0603_1608Metric_Pad0.98x0.95mm_HandSolder; Rating W
U5: TPS5450; SOIC-8-1EP_3.9x4.9mm_P1.27mm_EP2.29x3mm

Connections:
+6V: C22.1, C23.2 (-), L1.2 (-), R17.1 (+); also elsewhere on the board
/TPS5450/VSENSE: R17.2 (-), R18.1 (+), U5.4 (VSENSE)
GNDPWR: C20.1 (+), C21.1 (+), C22.2, C23.1 (+), D16.2 (A), R18.2 (-), U5.6 (GND), U5.9 (PowePAD); also elsewhere on the board
unnamed: C19.1 (+), U5.1 (BOOT)
unnamed: C19.2 (-), D16.1 (K), L1.1 (+), U5.8 (PH)
VBAT: C20.2 (-), C21.2 (-), U5.7 (VIN); also elsewhere on the board

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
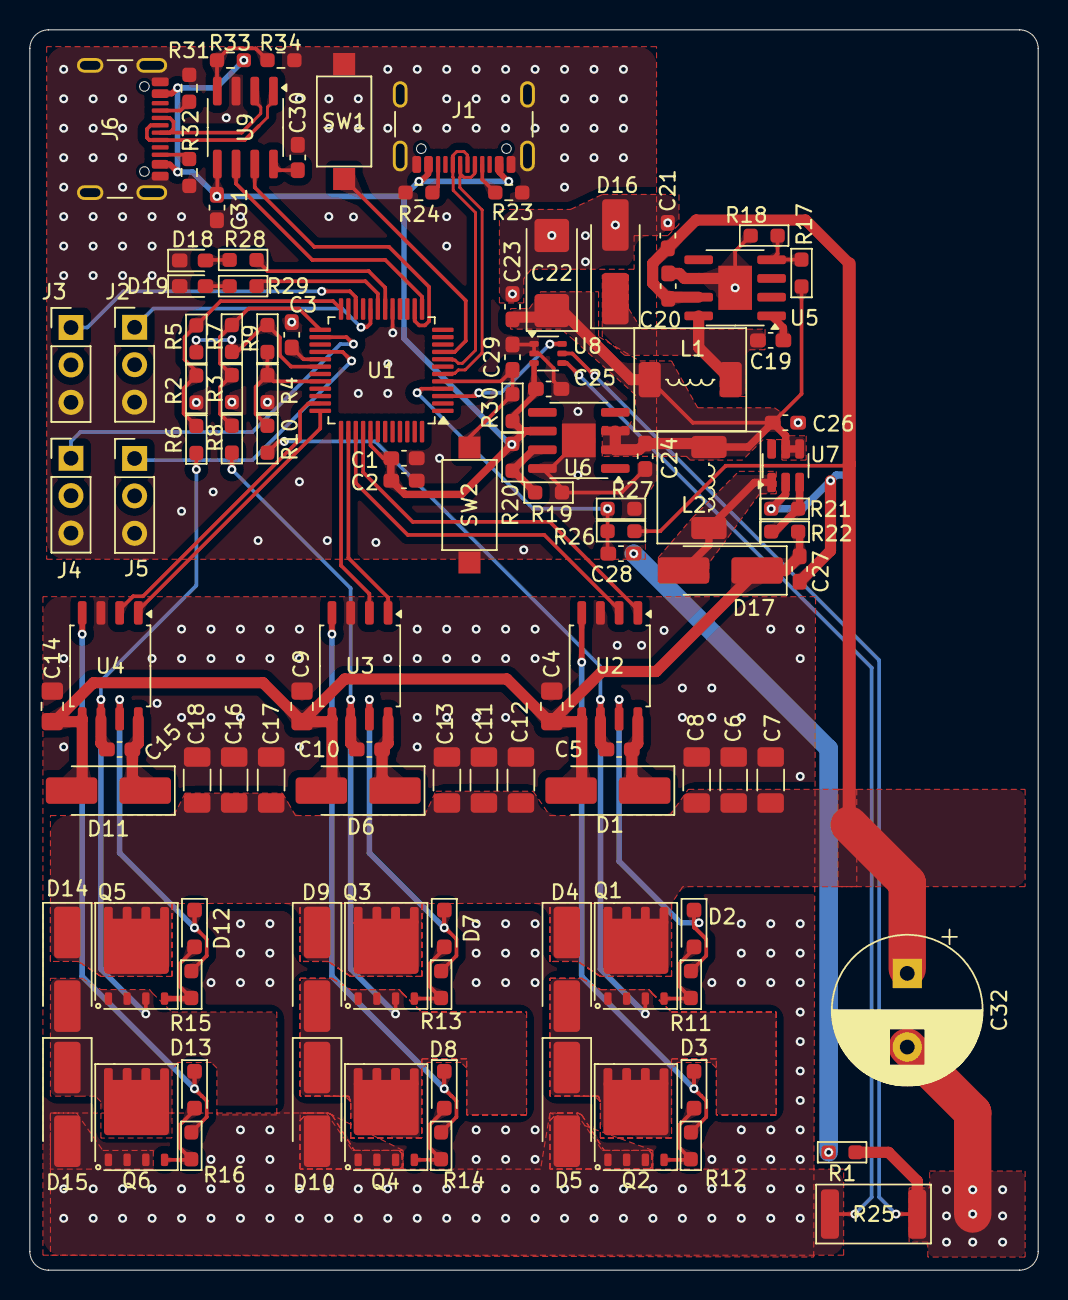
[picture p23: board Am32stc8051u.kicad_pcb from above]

Board: 2 copper layers, 68.5 x 84.2 mm, 110 parts (0 on the bottom side), 66 nets.

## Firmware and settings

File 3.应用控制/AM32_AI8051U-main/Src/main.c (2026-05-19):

#include "main.h"
#include "commutate.h"
#include "eeprom.h"
#include "mcu.h"
#include "targets.h"
#include "sounds.h"
#include "phaseouts.h"
#include "input.h"
#include "stc8051u_it.h"
#include "peripherals.h"
#include "kiss_telemetry.h"
#include "functions.h"
#include "adc.h"

#include "stdio.h"
#include "string.h"
#include "version.h"

// Flags
bool armed = 0;
bool crawler_mode = 0;
bool send_telemetry = 0; // 发送遥测标志
bool send_esc_info_flag = 0;
bool maximum_throttle_change_ramp = 1;
uint8_t drive_by_rpm = 0;
uint8_t use_speed_control_loop = 0;
uint8_t running = 0;
uint8_t fast_accel = 0;
int8_t startup_boost = 50;
int8_t reversing_dead_band = 1;
uint16_t enter_sine_angle = 180;

// Speed Control
uint32_t MINIMUM_RPM_SPEED_CONTROL = 1000;
uint32_t MAXIMUM_RPM_SPEED_CONTROL = 100000;

// PID Controllers
fastPID speedPid = { // commutation speed loop time
        { 0 },		  // err
        { 10 },       // kp
        { 0 },        // ki
        { 100 },      // kd
        { 0 }, 		  // integral
        { 0 },  	  // derivative
        { 0 }, 		  // last_error
        { 0 },        // pid_output
        { 10000 },    // integral_limit
        { 50000 }     // output_limit
};

fastPID currentPid = { // 1khz loop time
        { 0 },        // err
        { 400 },      // kp
        { 0 },        // ki
        { 1000 },     // kd
        { 0 }, 		  // integral
        { 0 },  	  // derivative
        { 0 }, 		  // last_error
        { 0 },        // pid_output
        { 20000 },    // integral_limit
        { 100000 }    // output_limit
};

fastPID stallPid = { // 1khz loop time
        { 0 },  	  // err
        { 1 },        // kp
        { 0 },        // ki
        { 50 },       // kd
        { 0 }, 		  // integral
        { 0 },  	  // derivative
        { 0 }, 		  // last_error
        { 0 },        // pid_output
        { 10000 },    // integral_limit
        { 50000 }     // output_limit
};

// RPM and Timing
uint16_t e_rpm;
uint16_t k_erpm;
uint32_t e_com_time;
uint32_t target_e_com_time;

// Battery and Current
uint8_t cell_count = 0; // 电池计数器
uint16_t battery_voltage = 0; // 电池电压
int16_t actual_current = 0; // 实际电流
float consumed_current = 0; // 消耗电流
int16_t use_current_limit_adjust; // 电流限制
uint8_t degrees_celsius;

// Stall Protection
float stall_protection_adjust;
uint16_t stall_protect_target_interval = TARGET_STALL_PROTECTION_INTERVAL;

// Telemetry
uint16_t telem_ms_count = 0; // 遥测计数器
uint8_t telemetry_interval_ms = 30; // 遥测间隔

// Counters
uint8_t adc_counter = 0;
uint16_t ledcounter = 0; // LED计数器
uint16_t one_khz_loop_counter = 0; // 1KHz计数器
uint16_t tenkhzcounter = 0; // 20KHz计数器
uint16_t signaltimeout = 0; // 信号计数器
uint16_t low_voltage_count = 0; // 低电压计数器
uint16_t armed_timeout_count = 0; // 握手超时计数器


void tenKhzRoutine(void){
	duty_cycle = duty_cycle_setpoint;
	tenkhzcounter++;
	ledcounter++;
	one_khz_loop_counter++;
	if (!armed) {
		if (cell_count == 0) {
			if (inputSet) {
				if (adjusted_input == 0) {
					armed_timeout_count++;
					if (armed_timeout_count > LOOP_FREQUENCY_HZ) { // one second
						if (zero_input_count > 30) {
							armed = 1;
#ifdef USE_LED_STRIP
                            //	send_LED_RGB(0,0,0);
                            delayMicros(1000);
                            send_LED_RGB(0, 255, 0);
#endif
#ifdef USE_RGB_LED
                            GPIOB->BRR = LL_GPIO_PIN_3; // turn on green
                            GPIOB->BSRR = LL_GPIO_PIN_8; // turn on green
                            GPIOB->BSRR = LL_GPIO_PIN_5;
#endif
							if ((cell_count == 0) && LOW_VOLTAGE_CUTOFF) {
								static uint8_t i;
								cell_count = battery_voltage / 370;
								for (i = 0; i < cell_count; i++) {
									playInputTune();
									delayMillis(100);
									RELOAD_WATCHDOG_COUNTER();
								}
							} else {
#ifdef MCU_AT415
								play_tone_flag = 4;
#else
								playInputTune();
#endif
							}
							if (!servoPwm) {
								eepromBuffer.eeppack.rc_car_reverse = 0;
							}
						} else {
							inputSet = 0;
							armed_timeout_count = 0;
						}
					}
				} else {
					armed_timeout_count = 0;
				}
			}
		}
	}

	if (eepromBuffer.eeppack.telemetry_on_interval) {
        telem_ms_count++;
        if (telem_ms_count > ((telemetry_interval_ms - 1 + eepromBuffer.eeppack.telemetry_on_interval) * 20)) {
            // telemetry_on_interval = 1 is a boolean, but it can also be 2 or more to indicate an identifier
            // by making the interval just slightly different with an unique identifier, we can guarantee that many ESCs can communicate on just one signal
            // there will be some collisions but not as many as if two ESCs always tried to talk at once.
            send_telemetry = 1;
            telem_ms_count = 0;
        }
	}

#ifndef BRUSHED_MODE

	if (!stepper_sine) {
#ifndef CUSTOM_RAMP
		if (old_routine && running) {
			// send_LED_RGB(255, 0, 0);
			maskPhaseInterrupts();
			getBemfState();
			if (!zcfound) {
				if (rising) {
					if (bemfcounter > min_bemf_counts_up) {
						zcfound = 1;
						zcfoundroutine();
					}
				} else {
					if (bemfcounter > min_bemf_counts_down) {
						zcfound = 1;
						zcfoundroutine();
					}
				}
			}
		}
#endif
		if (one_khz_loop_counter > PID_LOOP_DIVIDER) { // 1khz PID loop
			one_khz_loop_counter = 0;
            if (use_current_limit && running) {
                use_current_limit_adjust -= (int16_t)(doPidCalculations(&currentPid, actual_current,
                                                          eepromBuffer.eeppack.limits.current * 2 * 100)
                    / 10000);
                if (use_current_limit_adjust < minimum_duty_cycle) {
                    use_current_limit_adjust = minimum_duty_cycle;
                }
                if (use_current_limit_adjust > 2000) {
                    use_current_limit_adjust = 2000;
                }
            }

			if (eepromBuffer.eeppack.stall_protection && running) { // this boosts throttle as the rpm gets lower, for crawlers
												// and rc cars only, do not use for multirotors.
				stall_protection_adjust += (doPidCalculations(&stallPid, commutation_interval,
                                                stall_protect_target_interval));
                if (stall_protection_adjust > 150UL * 10000) {
                    stall_protection_adjust = 150UL * 10000;
                }
                if (stall_protection_adjust <= 0) {
                    stall_protection_adjust = 0;
                }
			}
			if (use_speed_control_loop && running) {
                input_override += doPidCalculations(&speedPid, e_com_time, target_e_com_time);
                if (input_override > 2047UL * 10000) {
                    input_override = 2047UL * 10000;
                }
                if (input_override < 0) {
                    input_override = 0;
                }
                if (zero_crosses < 100) {
                    speedPid.integral = 0;
                }
			}
		}
		if (maximum_throttle_change_ramp) {
			//	max_duty_cycle_change = map(k_erpm, low_rpm_level,
            // high_rpm_level, 1, 40);
#ifdef VOLTAGE_BASED_RAMP
            uint16_t voltage_based_max_change = map(battery_voltage, 800, 2200, 10, 1);
            if (average_interval > 200) {
                max_duty_cycle_change = voltage_based_max_change;
            } else {
                max_duty_cycle_change = voltage_based_max_change * 3;
            }
#else
            if (zero_crosses < 150 || last_duty_cycle < 150) {   
                max_duty_cycle_change = RAMP_SPEED_STARTUP;
            } else {
                if (average_interval > 500) {
                    max_duty_cycle_change = RAMP_SPEED_LOW_RPM;
                } else {
                    max_duty_cycle_change = RAMP_SPEED_HIGH_RPM;
                }
            }
#endif
#ifdef CUSTOM_RAMP
   //         max_duty_cycle_change = eepromBuffer[30];
#endif
            if ((duty_cycle - last_duty_cycle) > max_duty_cycle_change) {
                duty_cycle = last_duty_cycle + max_duty_cycle_change;
                if (commutation_interval > 500) {
                    fast_accel = 1;
					temp_advance = eepromBuffer.eeppack.advance_level;
                } else {
                    fast_accel = 0;
                }

            } else if ((last_duty_cycle - duty_cycle) > max_duty_cycle_change) {
                duty_cycle = last_duty_cycle - max_duty_cycle_change;
                fast_accel = 0;
				temp_advance = eepromBuffer.eeppack.advance_level;
            } else {
				if(duty_cycle < 300 && commutation_interval < 300){
					temp_advance = eepromBuffer.eeppack.advance_level;
				}else{
					temp_advance =  eepromBuffer.eeppack.advance_level;
				}

                fast_accel = 0;
            }
		}
		if ((armed && running) && input > 47) {
			if (eepromBuffer.eeppack.variable_pwm) {
			}
			adjusted_duty_cycle = ((duty_cycle * pwm_arr) / 2000) + 1;

		} else {

			if (prop_brake_active) {
				adjusted_duty_cycle = PWM_MAX_ARR - ((prop_brake_duty_cycle * pwm_arr) / 2000) + 1;
			} else {
				adjusted_duty_cycle = ((duty_cycle * pwm_arr) / 2000);
			}
		}
		last_duty_cycle = duty_cycle;
		SET_AUTO_RELOAD_PWM(pwm_arr);
		SET_DUTY_CYCLE_ALL(adjusted_duty_cycle);
	}
#endif // ndef brushed_mode
#if defined(FIXED_DUTY_MODE) || defined(FIXED_SPEED_MODE)
    if (getInputPinState()) {
        signaltimeout++;
        if (signaltimeout > LOOP_FREQUENCY_HZ) {
            NVIC_SystemReset();
        }
    } else {
        signaltimeout = 0;
    }
#else
    signaltimeout++;

#endif
}


static void checkDeviceInfo(void) {
#define DEVINFO_MAGIC1 0x5925e3da
#define DEVINFO_MAGIC2 0x4eb863d9

	const struct devinfo {
		uint32_t magic1;
		uint32_t magic2;
		const uint8_t deviceInfo[9];
	} *devinfo = (struct devinfo*) (0xFF1000 - 32);

	if (devinfo->magic1 != DEVINFO_MAGIC1 || devinfo->magic2 != DEVINFO_MAGIC2) {
		// bootloader does not support this feature, nothing to do
		return;
	}
	// change eeprom_address based on the code in the bootloaders device info
	switch (devinfo->deviceInfo[4]) {
	case 0x1f:
		eeprom_address = 0xFF7C00;
		break;
	case 0x35:
		eeprom_address = 0xFFF800;
		break;
	case 0x2b:
		eeprom_address = 0xFFF800;
		break;
	}

// 	// TODO: check pin code and reboot to bootloader if incorrect
}
/**********************************************/
void main(void)
{
	initAfterJump();

	checkDeviceInfo();

	initCorePeripherals();

	// enableCorePeripherals();

	loadEEpromSettings();


    if (VERSION_MAJOR != eepromBuffer.eeppack.version.major || 
		VERSION_MINOR != eepromBuffer.eeppack.version.minor || 
		eeprom_layout_version > eepromBuffer.eeppack.eeprom_version) {
        eepromBuffer.eeppack.version.major = VERSION_MAJOR;
        eepromBuffer.eeppack.version.minor = VERSION_MINOR;
       	strncpy(eepromBuffer.eeppack.firmware_name, FIRMWARE_NAME, 12);
        saveEEpromSettings();
    }

	if (eepromBuffer.eeppack.dir_reversed == 1) {
		forward = 0;
	} else {
		forward = 1;
	}

	pwm_arr = PWM_MAX_ARR;

	if (!eepromBuffer.eeppack.comp_pwm) {
		eepromBuffer.eeppack.use_sine_start = 0; // sine start requires complementary pwm.
	}

	if (eepromBuffer.eeppack.rc_car_reverse) { // overrides a whole lot of things!
		throttle_max_at_low_rpm = 1000;
		eepromBuffer.eeppack.bi_direction = 1;
		eepromBuffer.eeppack.use_sine_start = 0;
		low_rpm_throttle_limit= 1;
		eepromBuffer.eeppack.variable_pwm = 0;
		// eepromBuffer.eeppack.stall_protection = 1;
		eepromBuffer.eeppack.comp_pwm = 0;
		eepromBuffer.eeppack.stuck_rotor_protection = 0;
        minimum_duty_cycle = minimum_duty_cycle + 50;
        stall_protect_minimum_duty = stall_protect_minimum_duty + 50;
        min_startup_duty = min_startup_duty + 50;
	}

#ifdef MCU_F031
    GPIOF->BSRR = LL_GPIO_PIN_6; // uncomment to take bridge out of standby mode
                                 // and set oc level
    GPIOF->BRR = LL_GPIO_PIN_7; // out of standby mode
    GPIOA->BRR = LL_GPIO_PIN_11;
#endif
#ifdef MCU_G031
    GPIOA->BRR = LL_GPIO_PIN_11;
    GPIOA->BSRR = LL_GPIO_PIN_12;    // Pa12 attached to enable on dev board
#endif
#ifdef USE_LED_STRIP
    send_LED_RGB(125, 0, 0);
#endif

#ifdef USE_CRSF_INPUT
    inputSet = 1;
    playStartupTune();
    MX_IWDG_Init();
    LL_IWDG_ReloadCounter(IWDG);
#else
#if defined(FIXED_DUTY_MODE) || defined(FIXED_SPEED_MODE)
    MX_IWDG_Init();
    RELOAD_WATCHDOG_COUNTER();
    inputSet = 1;
    armed = 1;
    adjusted_input = 48;
    newinput = 48;
		comStep(2);
#ifdef FIXED_SPEED_MODE
    use_speed_control_loop = 1;
    eepromBuffer.use_sine_start = 0;
    target_e_com_time = 60000000 / FIXED_SPEED_MODE_RPM / (eepromBuffer.motor_poles / 2);
    input = 48;
#endif

#else
#ifdef BRUSHED_MODE
    // bi_direction = 1;
    commutation_interval = 5000;
    eepromBuffer.use_sine_start = 0;
    maskPhaseInterrupts();
    playBrushedStartupTune();
#else
#ifdef MCU_AT415
    play_tone_flag = 5;
#else
    playStartupTune();
#endif
#endif
	zero_input_count = 0;
	IWDG_Init();
	RELOAD_WATCHDOG_COUNTER();
#ifdef GIMBAL_MODE
    eepromBuffer.bi_direction = 1;
    eepromBuffer.use_sine_start = 1;
#endif

#ifdef USE_ADC_INPUT
    armed_count_threshold = 5000;
    inputSet = 1;
#else
	receiveDmaBuffer();
	if (drive_by_rpm) {
		use_speed_control_loop = 1;
	}
#endif

#endif // end fixed duty mode ifdef
#endif // end crsf input

#ifdef MCU_F051
    MCU_Id = DBGMCU->IDCODE &= 0xFFF;
    REV_Id = DBGMCU->IDCODE >> 16;

    if (REV_Id >= 4096) {
        temperature_offset = 0;
    } else {
        temperature_offset = 230;
    }

#endif
#ifdef NEUTRONRC_G071
    setInputPullDown();
#else
	setInputPullUp();
#endif

#ifdef USE_STARTUP_BOOST
	min_startup_duty = min_startup_duty + 200 + ((eepromBuffer.eeppack.pwm_frequency * 100)/24);
	minimum_duty_cycle = minimum_duty_cycle + 50 + ((eepromBuffer.eeppack.pwm_frequency * 50 )/24);
	startup_max_duty_cycle = startup_max_duty_cycle + 400;
#endif

	while (1)
	{	
		e_com_time = (commutation_intervals[0] + commutation_intervals[1] + 
				  	  commutation_intervals[2] + commutation_intervals[3] + 
				  	  commutation_intervals[4] + commutation_intervals[5] + 4) >> 1;
#if defined(FIXED_DUTY_MODE) || defined(FIXED_SPEED_MODE)
        setInput();
#endif

#ifdef NEED_INPUT_READY
        if (input_ready) {
            processDshot();
            input_ready = 0;
        }
#endif
		if(zero_crosses < 5){
	  		min_bemf_counts_up = TARGET_MIN_BEMF_COUNTS * 2;
			min_bemf_counts_down = TARGET_MIN_BEMF_COUNTS * 2;
		}else{
	 		min_bemf_counts_up = TARGET_MIN_BEMF_COUNTS;
			min_bemf_counts_down = TARGET_MIN_BEMF_COUNTS;
		}

		RELOAD_WATCHDOG_COUNTER();

		if (eepromBuffer.eeppack.variable_pwm) {
			pwm_arr = map(commutation_interval,96,200,PWM_MAX_ARR / 2,PWM_MAX_ARR);
		}
        if (eepromBuffer.eeppack.variable_pwm == 2) {      // uses automatic range   
			if(average_interval < 250 && average_interval > 100){
				pwm_arr = average_interval * (CPU_FREQUENCY_MHZ/9);
			}
			if(average_interval < 100 && average_interval > 0){
				pwm_arr = 100 * (CPU_FREQUENCY_MHZ/9);
			}
			if((average_interval >= 250) || (average_interval == 0)){
				pwm_arr = 250 * (CPU_FREQUENCY_MHZ/9);
			} 
        }
		if (signaltimeout > (LOOP_FREQUENCY_HZ >> 1)) { // half second timeout when armed;
			static uint8_t i;
			if (armed) {
				allOff();
				armed = 0;
				input = 0;
				inputSet = 0;
				zero_input_count = 0;
				SET_DUTY_CYCLE_ALL(0);
				resetInputCaptureTimer();
				for (i = 0; i < 64; i++) {
					dma_buffer[i] = 0;
				}
				NVIC_SystemReset();
			}
			if (signaltimeout > LOOP_FREQUENCY_HZ << 1) { // 2 second when not armed
				allOff();
				armed = 0;
				input = 0;
				inputSet = 0;
				zero_input_count = 0;
				SET_DUTY_CYCLE_ALL(0);
				resetInputCaptureTimer();
				for (i = 0; i < 64; i++) {
					dma_buffer[i] = 0;
				}
				NVIC_SystemReset();
			}
		}
#ifdef USE_CUSTOM_LED
        if ((input >= 47) && (input < 1947)) {
            if (ledcounter > (2000 >> forward)) {
                GPIOB->BSRR = LL_GPIO_PIN_3;
            } else {
                GPIOB->BRR = LL_GPIO_PIN_3;
            }
            if (ledcounter > (4000 >> forward)) {
                ledcounter = 0;
            }
        }
        if (input > 1947) {
            GPIOB->BSRR = LL_GPIO_PIN_3;
        }
        if (input < 47) {
            GPIOB->BRR = LL_GPIO_PIN_3;
        }
#endif

		if (tenkhzcounter > LOOP_FREQUENCY_HZ) { // 1s sample interval 10000
			consumed_current = (float) actual_current / 360.0 + consumed_current;
			tenkhzcounter = 0;
		}

#ifndef BRUSHED_MODE

		if ((zero_crosses > 1000) || (adjusted_input == 0)) {
			bemf_timeout_happened = 0;
		}
		if (zero_crosses > 100 && adjusted_input < 200) {
			bemf_timeout_happened = 0;
		}
		if (eepromBuffer.eeppack.use_sine_start && adjusted_input < 160) {
			bemf_timeout_happened = 0;
		}

        if (crawler_mode) {
            if (adjusted_input < 400) {
                bemf_timeout_happened = 0;
            }
        } else {
            if (adjusted_input < 150) { // startup duty cycle should be low enough to not burn motor
                bemf_timeout = 100;
            } else {
                bemf_timeout = 10;
            }
        }
#endif
        average_interval = e_com_time / 3;
        if (desync_check && zero_crosses > 10) {
            if ((getAbsDif(last_average_interval, average_interval) > average_interval >> 1) && (average_interval < 2000)) { // throttle resitricted before zc 20.
                zero_crosses = 0;
                desync_happened++;
                if ((!eepromBuffer.eeppack.bi_direction && (input > 47)) || commutation_interval > 1000) {
                    running = 0;
                }
                old_routine = 1;
                if (zero_crosses > 100) {
                    average_interval = 5000;
                }
                last_duty_cycle = min_startup_duty / 2;
            }
            desync_check = 0;
            //	}
            last_average_interval = average_interval;
        }

#if !defined(MCU_G031) && !defined(NEED_INPUT_READY)
        // if (dshot_telemetry && (commutation_interval > DSHOT_PRIORITY_THRESHOLD)) {
        //      NVIC_SetPriority(IC_DMA_IRQ_NAME, 0);
        //      NVIC_SetPriority(COM_TIMER_IRQ, 1);
        //      NVIC_SetPriority(COMPARATOR_IRQ, 1);
        //  } else {
        //      NVIC_SetPriority(IC_DMA_IRQ_NAME, 1);
        //      NVIC_SetPriority(COM_TIMER_IRQ, 0);
        //      NVIC_SetPriority(COMPARATOR_IRQ, 0);
        //  }
#endif

		if (send_telemetry) {
#ifdef USE_SERIAL_TELEMETRY
			makeTelemPackage(degrees_celsius, battery_voltage, actual_current,consumed_current, e_rpm);
			send_telem_DMA();
			send_telemetry = 0;
#endif
		}else if (send_esc_info_flag){
			
		}

		adc_counter++;
		if (DMA_ADC_STA) { // for adc and telemetry
#if defined(STMICRO)
            ADC_DMA_Callback();
            LL_ADC_REG_StartConversion(ADC1);
            converted_degrees = __LL_ADC_CALC_TEMPERATURE(3300, ADC_raw_temp, LL_ADC_RESOLUTION_12B);
#endif
#ifdef MCU_GDE23
            ADC_DMA_Callback();
            // converted_degrees = (1.43 - ADC_raw_temp * 3.3 / 4096) * 1000 / 4.3 + 25;
            converted_degrees = ((int32_t)(357.5581395348837f * (1 << 16)) - ADC_raw_temp * (int32_t)(0.18736373546511628f * (1 << 16))) >> 16;
            adc_software_trigger_enable(ADC_REGULAR_CHANNEL);
#endif
#ifdef ARTERY
            ADC_DMA_Callback();
            adc_ordinary_software_trigger_enable(ADC1, TRUE);
            converted_degrees = getConvertedDegrees(ADC_raw_temp);
#endif
#ifdef WCH
            startADCConversion( );
            converted_degrees = getConvertedDegrees(ADC_raw_temp);
#endif
#ifdef STC
			ADC_DMA_Callback();
#endif
			degrees_celsius;
			battery_voltage = (uint32_t)((7 * battery_voltage) + (((float)ADC_raw_volts * 5000 / 4095 * TARGET_VOLTAGE_DIVIDER) / 100)) >> 3;
			actual_current = (((float)ADC_raw_current * 5000 / 41) - (CURRENT_OFFSET * 100)) / (MILLIVOLT_PER_AMP);
			if (actual_current < 0) {
				actual_current = 0;
			}
			if (LOW_VOLTAGE_CUTOFF) {
				if (battery_voltage < (cell_count * low_cell_volt_cutoff)) {
					low_voltage_count++;
					if (low_voltage_count > (20000 - (stepper_sine * 900))) {
						input = 0;
						allOff();
						maskPhaseInterrupts();
						running = 0;
						zero_input_count = 0;
						armed = 0;
					}
				} else {
					low_voltage_count = 0;
				}
			}
            adc_counter = 0;
			DMA_ADC_STA = 0x00;
			Activate_ADC_DMA();
#ifdef USE_ADC_INPUT
            if (ADC_raw_input < 10) {
                zero_input_count++;
            } else {
                zero_input_count = 0;
            }
#endif
		}
#ifdef USE_ADC_INPUT
        signaltimeout = 0;
        ADC_smoothed_input = (((10 * ADC_smoothed_input) + ADC_raw_input) / 11);
        newinput = ADC_smoothed_input / 2;
        if (newinput > 2000) {
            newinput = 2000;
        }
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

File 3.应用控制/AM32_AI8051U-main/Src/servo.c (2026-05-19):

#include "main.h"
#include "eeprom.h"
#include "sounds.h"
#include "targets.h"
#include "servo.h"

#include "functions.h"
#include "input.h"

uint8_t calibration_required; 				// calibration required
uint8_t high_calibration_set = 0; 				// high calibration set
uint8_t enter_calibration_counter = 0; 			// enter calibration count	
uint8_t high_calibration_counts = 0; 			// high calibration counter
uint8_t low_calibration_counter = 0; 			// low calibration counter
int16_t last_high_threshold = 0; 				// last high threshold
int16_t servorawinput; 					// raw servo input
int16_t max_servo_deviation = 250;	// max deviation between two servo pulses


void UN_PWMB_Init(void) {
	register PWM_TypeDef *PWMB = PWMB_ADDRESS;

	gpio_mode_set(INPUT_PIN_PORT,INPUT_MODE_PIN,GPIO_Mode_IN_FLOATING);
	
	PWMB_PS = INPUT_PS;
	PWMB->PSCRH = 0x00;
	PWMB->PSCRL = CPU_FREQUENCY_MHZ - 1;
	PWMB->CCER1 = 0x00;
	PWMB->CCER2 = 0x00;


	PWMB->CCMR1 = 0x01;
	PWMB->CCMR2 = 0x02;
	PWMB->CCER1 = 0x31;

	PWMB->ARRH = 0xFF;
	PWMB->ARRL = 0xFF;
	PWMB->IER = 0x04;

	PPWMBH = 1;PPWMB = 0;

	PWMB->EGR = 0x01;
	PWMB->CR1 = 0x01;
}

void servoDmaBuffer(void) {
	register PWM_TypeDef *PWMB = PWMB_ADDRESS;
	PWMB->PSCRH = ic_timer_prescaler >> 8;
	PWMB->PSCRL = ic_timer_prescaler;
	PWMB->EGR = 0x01; 
}

void computeServoInput(void) {
	if (((dma_buffer[1] - dma_buffer[0]) > 800) && ((dma_buffer[1] - dma_buffer[0]) < 2200)) {
		signaltimeout = 0;
		if (calibration_required) {
			if (!high_calibration_set) {
				if (high_calibration_counts == 0) {
					last_high_threshold = dma_buffer[1] - dma_buffer[0];
				}
				high_calibration_counts++;
				if (getAbsDif(last_high_threshold, servo_high_threshold) > 50) {
					calibration_required = 0;
				} else {
					servo_high_threshold = ((7 * servo_high_threshold + (dma_buffer[1] - dma_buffer[0])) >> 3);
					if (high_calibration_counts > 50) {
						servo_high_threshold = servo_high_threshold - 25;
						eepromBuffer.eeppack.servo.high_threshold = (servo_high_threshold - 1750) / 2;
						high_calibration_set = 1;
						playDefaultTone();
					}
				}
				last_high_threshold = servo_high_threshold;
			}
			if (high_calibration_set) {
				if (dma_buffer[1] - dma_buffer[0] < 1250) {
					low_calibration_counter++;
					servo_low_threshold = ((7 * servo_low_threshold + (dma_buffer[1] - dma_buffer[0])) >> 3);
				}
				if (low_calibration_counter > 75) {
					servo_low_threshold = servo_low_threshold + 25;
					eepromBuffer.eeppack.servo.low_threshold = (servo_low_threshold - 750) / 2;
					calibration_required = 0;
					saveEEpromSettings();
					low_calibration_counter = 0;
					playChangedTone();
				}
			}
			signaltimeout = 0;
		} else {
			if (eepromBuffer.eeppack.bi_direction) {
				if (dma_buffer[1] - dma_buffer[0] <= servo_neutral) {
					servorawinput = map((dma_buffer[1] - dma_buffer[0]),servo_low_threshold, servo_neutral, 0, 1000);
				} else {
					servorawinput = map((dma_buffer[1] - dma_buffer[0]),servo_neutral + 1, servo_high_threshold, 1001,2000);
				}
			} else {
				servorawinput = map((dma_buffer[1] - dma_buffer[0]),servo_low_threshold, servo_high_threshold, 47, 2047);
				if (servorawinput <= 48) {
					servorawinput = 0;
				}
			}
			signaltimeout = 0;
		}
	} else {
		zero_input_count = 0; // reset if out of range
	}

	if (servorawinput - newinput > max_servo_deviation) {
		newinput += max_servo_deviation;
	} else if (newinput - servorawinput > max_servo_deviation) {
		newinput -= max_servo_deviation;
	} else {
		newinput = servorawinput;
	}

}

void checkServo(void) {
	if (smallestnumber > 200 && smallestnumber < 20000) {
		servoPwm = 1;
		ic_timer_prescaler = CPU_FREQUENCY_MHZ - 1;
		buffersize = 2;
		inputSet = 1;
		receiveDmaBuffer = servoDmaBuffer;
	}
}
